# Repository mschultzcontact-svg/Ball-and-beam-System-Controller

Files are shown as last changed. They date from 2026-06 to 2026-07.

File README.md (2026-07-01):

# Automatisiertes Kugelbahn-System – Fokus: Balancer-Modul (Ball-on-Beam)

## Über das Projekt
Dieses Repository dokumentiert ein mechatronisches Folgeprojekt am Labor für Mechatronik und Regelungstechnik der Hochschule Osnabrück. 

Das Gesamtsystem ist als geschlossener Kreislauf konzipiert. Die Kugeln durchlaufen kontinuierlich eine dreiteilige, modular aufgebaute automatisierte Kugelbahn:

1. **Magazin & SmartSort-Modul:** Zu Beginn werden die Billardkugeln in einem Magazin gesammelt und von dort aus einzeln dem Sortierbereich zugeführt. Ein kamerabasiertes KI-System zur Bildverarbeitung erkennt die optischen Merkmale der Kugeln. Anhand dieser Klassifizierung ordnet ein 2-Achs-Handhabungsarm die Kugeln einer von drei Führungen zu.
2. **Rückführungsmodul:** Über diese Führungen rollen die Kugeln weiter zum Rückführungsmodul. Ein mechanischer Lift transportiert die Kugeln vertikal nach oben auf eine höhere Ebene, von wo aus sie eigenständig zum Vereinzeler des darauffolgenden Moduls rollen.
3. **Balancer-Modul (Ball-on-Beam):** Dieses Modul bildet den Kern und Schwerpunkt dieser Arbeit. Nach der gezielten Freigabe der Kugel durch den Vereinzeler gelangt diese auf eine bewegliche Wippe. Die Kugel wird entlang dieser 1,5 Meter langen Achse transportiert, während ein Schrittmotor den Neigungswinkel der Wippe kontinuierlich anpasst.

**Die Kernaufgabe meines Projekts:** Da dieses Kugel-auf-Balken-System inhärent instabil ist, besteht die Herausforderung darin, das System präzise zu regeln. Im Rahmen der Projektphase wird zunächst eine zentrale Steuerbox zur Signalverarbeitung und Motoransteuerung entwickelt (Teil I). Darauf aufbauend wird im Zuge der Bachelorarbeit eine robuste Regelungsstrategie mittels MATLAB-Simulation entworfen und an der realen Anlage in Betrieb genommen (Teil II), um einen dauerhaft fehlerfreien Kreislaufbetrieb zu garantieren.

---

## Repository-Struktur & Inhalt

Dieses Repository ist in funktionale Bereiche unterteilt. Nachfolgend finden Sie eine Übersicht, welche Inhalte und Daten in den jeweiligen Ordnern hinterlegt sind:

### 📁 01_Hardware
Hier befindet sich die vollständige elektrotechnische und mechanische Entwicklung der Steuerbox.
* **Datenblätter:** Technische Spezifikationen aller verwendeten Komponenten (z. B. Schrittmotor, ToF-Sensor, Mikrocontroller).
* **Schaltplan & Layout:** Die in KiCad entwickelten Platinen-Layouts (PCB), Schaltungsentwürfe sowie die Stücklisten (BOM) für die Fertigung.
* **Gehäuse:** CAD- und STL-Dateien für das Gehäuse der Steuerbox (optimiert für den 3D-Druck).

### 📁 02_Software_Firmware
Enthält den gesamten Programmcode für den realen Anlagenbetrieb sowie die Systemeinrichtung.
* **Steuerbox_Firmware:** Der produktive C/C++ Code für den Mikrocontroller, welcher im normalen Regelbetrieb die Sensorwerte einliest und den Motor ansteuert.
* **Kalibrierung:** Spezifische Testskripte zur Sensor- und Aktorkalibrierung, um Messfehler (z. B. des ToF-Sensors) vorab softwareseitig zu kompensieren.

### 📁 03_Modellierung_Simulation
Die theoretische und simulative Basis für den Reglerentwurf.
* **Modellierung:** Mathematische Herleitungen und die physikalischen Differentialgleichungen des Kugel-auf-Balken-Systems.
* **Matlab_Simulink:** `.m`-Skripte und `.slx`-Simulationsmodelle. Hier wird das System virtuell abgebildet, um Reglerstrukturen methodisch zu bedaten und eine Stabilitätsanalyse durchzuführen.
* **Messdaten:** Reale Protokolle und Schwingungsdaten aus der Anlage, die für den Abgleich zwischen Modell und Realität (Systemidentifikation) genutzt werden.

### 📁 04_Regelungsstrategie
Dokumentation und Code-Basis der untersuchten Regelungsansätze.
* Hier sind die verschiedenen evaluierten Regelungskonzepte hinterlegt (z. B. klassischer PID-Regler, Kaskadenregelung oder Zustandsregler). Es wird dokumentiert, wie die Strategien auf Störeinflüsse reagieren (z. B. beim transienten Eintritt der Kugel in das Modul) und welche Strategie die beste Stabilität liefert.

### 📁 05_Dokumentation
Begleitmaterialien und schriftliche Ausarbeitungen.
* Enthält den schriftlichen Projektbericht (Teil I: Steuerbox-Entwicklung & Teil II: Bachelorarbeit-Konzept inklusive Pflichtenheft und Projektplanung) sowie wichtige Systemgrafiken und Schaubilder.

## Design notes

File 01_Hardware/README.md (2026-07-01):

# 📁 Hardware-Entwicklung & Komponenten (Balancer-Modul)

Dieser Ordner enthält die vollständige elektrotechnische Dokumentation, das Platinen-Layout (KiCad) und die Spezifikationen der verwendeten Hardware-Komponenten für das Balancer-Modul (Ball-on-Beam).

## ⚡ Spannungsversorgung & Überwachung
Die primäre Energieeinspeisung der Steuerbox erfolgt über ein **24V-Hauptnetzteil** (Hauptversorgung für den Schrittmotor). Für die Logik- und Sensorpegel wird die Spannung über zwei **DC-DC-Wandler** heruntergeregelt:
* **24V ➡️ 9V:** Versorgung des Servomotors Wippe.
* **24V ➡️ 5V:** Versorgung der Servomotors Vereinzler.

**Spannungsüberwachung:** Die drei Spannungsschienen (24V, 9V, 5V) werden permanent überwacht. Da die ESP32-Eingänge nur maximal 3,3V tolerieren, sind präzise **SMD-Widerstände als Spannungsteiler** vorgeschaltet.

---

## 🧠 Dual-Controller-Architektur
Um harte Echtzeit-Regelung und Netzwerkkommunikation sauber zu trennen, basiert die Steuerbox auf zwei miteinander kommunizierenden ESP32-Modulen:

### 1. ESP32-S3-ETH (Host- & Kommunikations-Controller)
* **Aufgabe:** Übergeordnete Steuerung, Ethernet-Kommunikation mit den anderen Kugelbahn-Modulen (SmartSort / Rückführung) und Statusüberwachung.
* **Peripherie:** * Ansteuerung eines **TFT-Displays** zur Status- und Fehleranzeige.
  * Analoge Überwachung der Spannungsversorgung (5V, 9V, 24V).
  * Status-LEDs (inkl. Vorwiderständen) und 2x **Boot-Taster** für manuelle Eingriffe.

### 2. ESP32-DevKitC (Regelungs-Controller)
* **Aufgabe:** Läuft im **MATLAB/Simulink-Kompatibilitätsmodus**. Er liest in festen Zeitschritten die Sensorwerte ein, berechnet den Regelalgorithmus und steuert die Aktoren direkt an.
* **Kommunikation:** Direkter Datenaustausch mit dem ESP32-S3-ETH zur Zustandssynchronisation.

---

## 🛠️ Sensorik & Aktorik (Komponentenübersicht)

Die mechatronischen Komponenten des Moduls teilen sich in sensorische Erfassungsorgane und ausführende Aktoren auf:

* **Sensorik (Erfassung):**
  * **Kugelpositionssensor:** Kontinuierliche Erfassung der exakten Ist-Position der Kugel auf der 1,5 Meter langen Wippe als primäre Regelgröße.
  * **Hallsensor:** Erfasst den aktuellen Neigungswinkel der Wippen-Achse (Winkelmessung), um dem Regler die Orientierung der Bahn zurückzumelden.
  * **ToF-Sensor:** Optische Abstandsmessung via Lichtlaufzeit zur Kugeldetektion im Einlaufbereich des Vereinzeler-Moduls.
  * **Endschalter (Kugelaufnahme / Kugelabgabe):** Mechanische Taster zur sicheren Zustandserkennung, wenn eine Kugel das Modul betritt oder verlässt.

* **Aktorik (Ausführung):**
  * **Schrittmotor + DM556 Treiber:** Der Hauptantrieb zur hochpräzisen und dynamischen Verstellung des Neigungswinkels der Wippen-Linearachse.
  * **Servo-Vereinzeler:** Steuert die mechanische Freigabe der wartenden Kugeln vor dem Eintritt in die Regelstrecke.
  * **Servo-Wippe:** Ein zusätzlicher Stellmotor, welcher direkt an der Wippenmechanik für spezifische Stell- oder Arretieraufgaben zuständig ist.
---

## 📋 Datenblatt-Verzeichnis (Links)

Alle originalen Hersteller-Datenblätter sind im Unterordner `01_Datenblaetter/` hinterlegt:

| Komponente | Funktion im System | Dokument (Lokal) |
| :--- | :--- | :--- |
| **ESP32-S3-ETH** | Host, Ethernet & Display | [Datasheet_ESP32-S3-ETH.pdf](01_Datenblaetter/Datasheet_ESP32-S3-ETH.pdf) |
| **ESP32-DevKitC** | Simulink Echtzeit-Regler | [Datasheet_ESP32_DevKitC.pdf](01_Datenblaetter/Datasheet_ESP32_DevKitC.pdf) |
| **DM556** | Schrittmotortreiber | [Manual_DM556_Driver.pdf](01_Datenblaetter/Manual_DM556_Driver.pdf) |
| **ToF-Sensor** | Einlauf-Detektion | [Datasheet_ToF_Sensor.pdf](01_Datenblaetter/Datasheet_ToF_Sensor.pdf) |
| **DC-DC Wandler** | Spannungsregelung 5V / 9V | [Datasheet_DCDC_Converter.pdf](01_Datenblaetter/Datasheet_DCDC_Converter.pdf) |

---

## 📂 Ordnerinhalt
* `/01_Datenblaetter`: PDFs aller mechatronischen Komponenten.
* `/02_Schaltplan_Layout`: KiCad-Projektdateien, Schaltpläne (Schaltplan-Review), Gerber-Dateien für die Platinenfertigung und Stückliste (BOM).
* `/03_Gehaeuse`: CAD-Modelle und STL-Dateien für den 3D-Druck der Steuerbox.

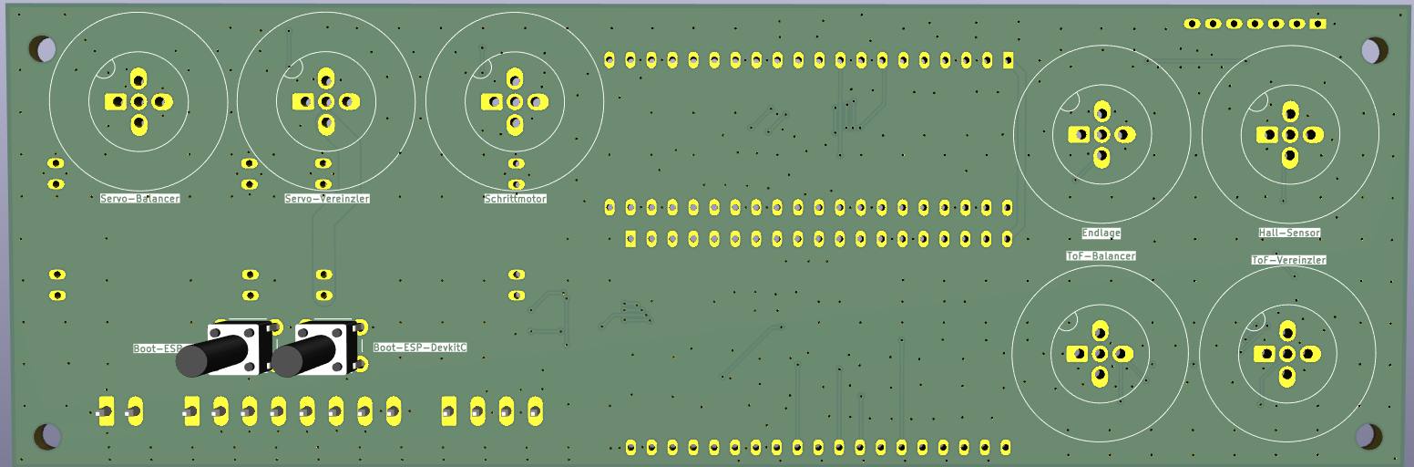
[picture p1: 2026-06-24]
01_Hardware/02_KiCad/Bilder_und_Schaltplan/Screenshot_Leiterplatte_3DAnsicht_Rückseite.png

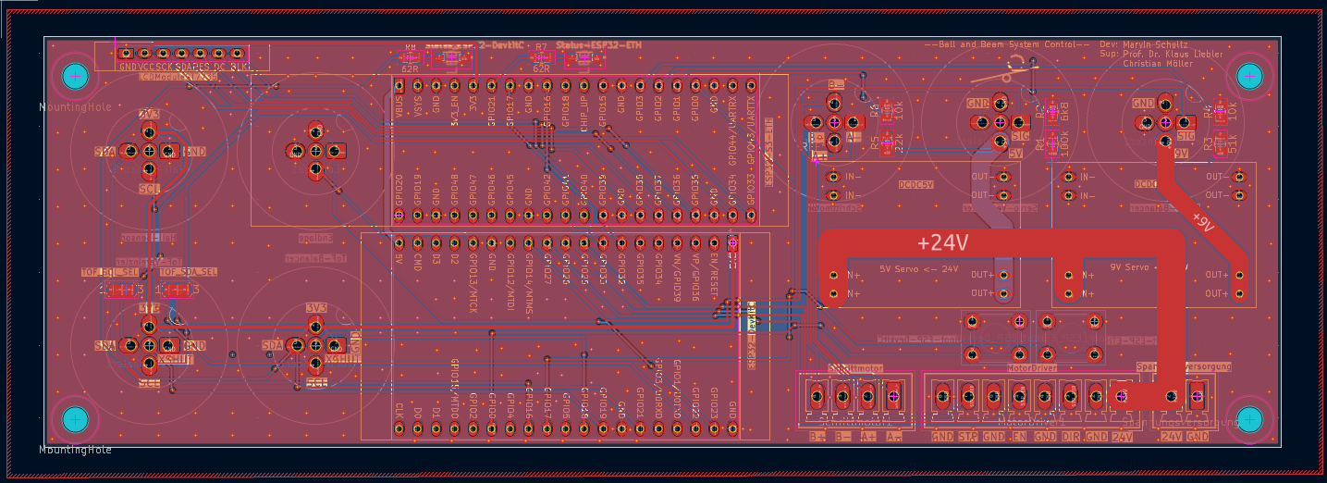
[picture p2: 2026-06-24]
01_Hardware/02_KiCad/Bilder_und_Schaltplan/Screenshot_Leiterplatte_Leiterplatteneditor.png

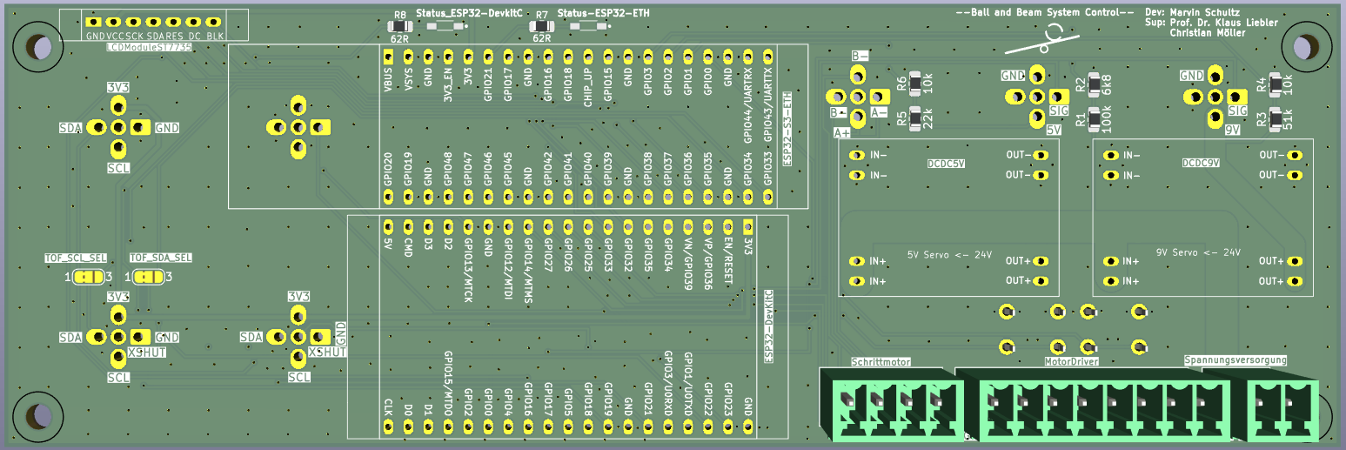
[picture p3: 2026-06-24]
01_Hardware/02_KiCad/Bilder_und_Schaltplan/Screenshot_Leiterplatte_3DAnsicht_Frontseite.png

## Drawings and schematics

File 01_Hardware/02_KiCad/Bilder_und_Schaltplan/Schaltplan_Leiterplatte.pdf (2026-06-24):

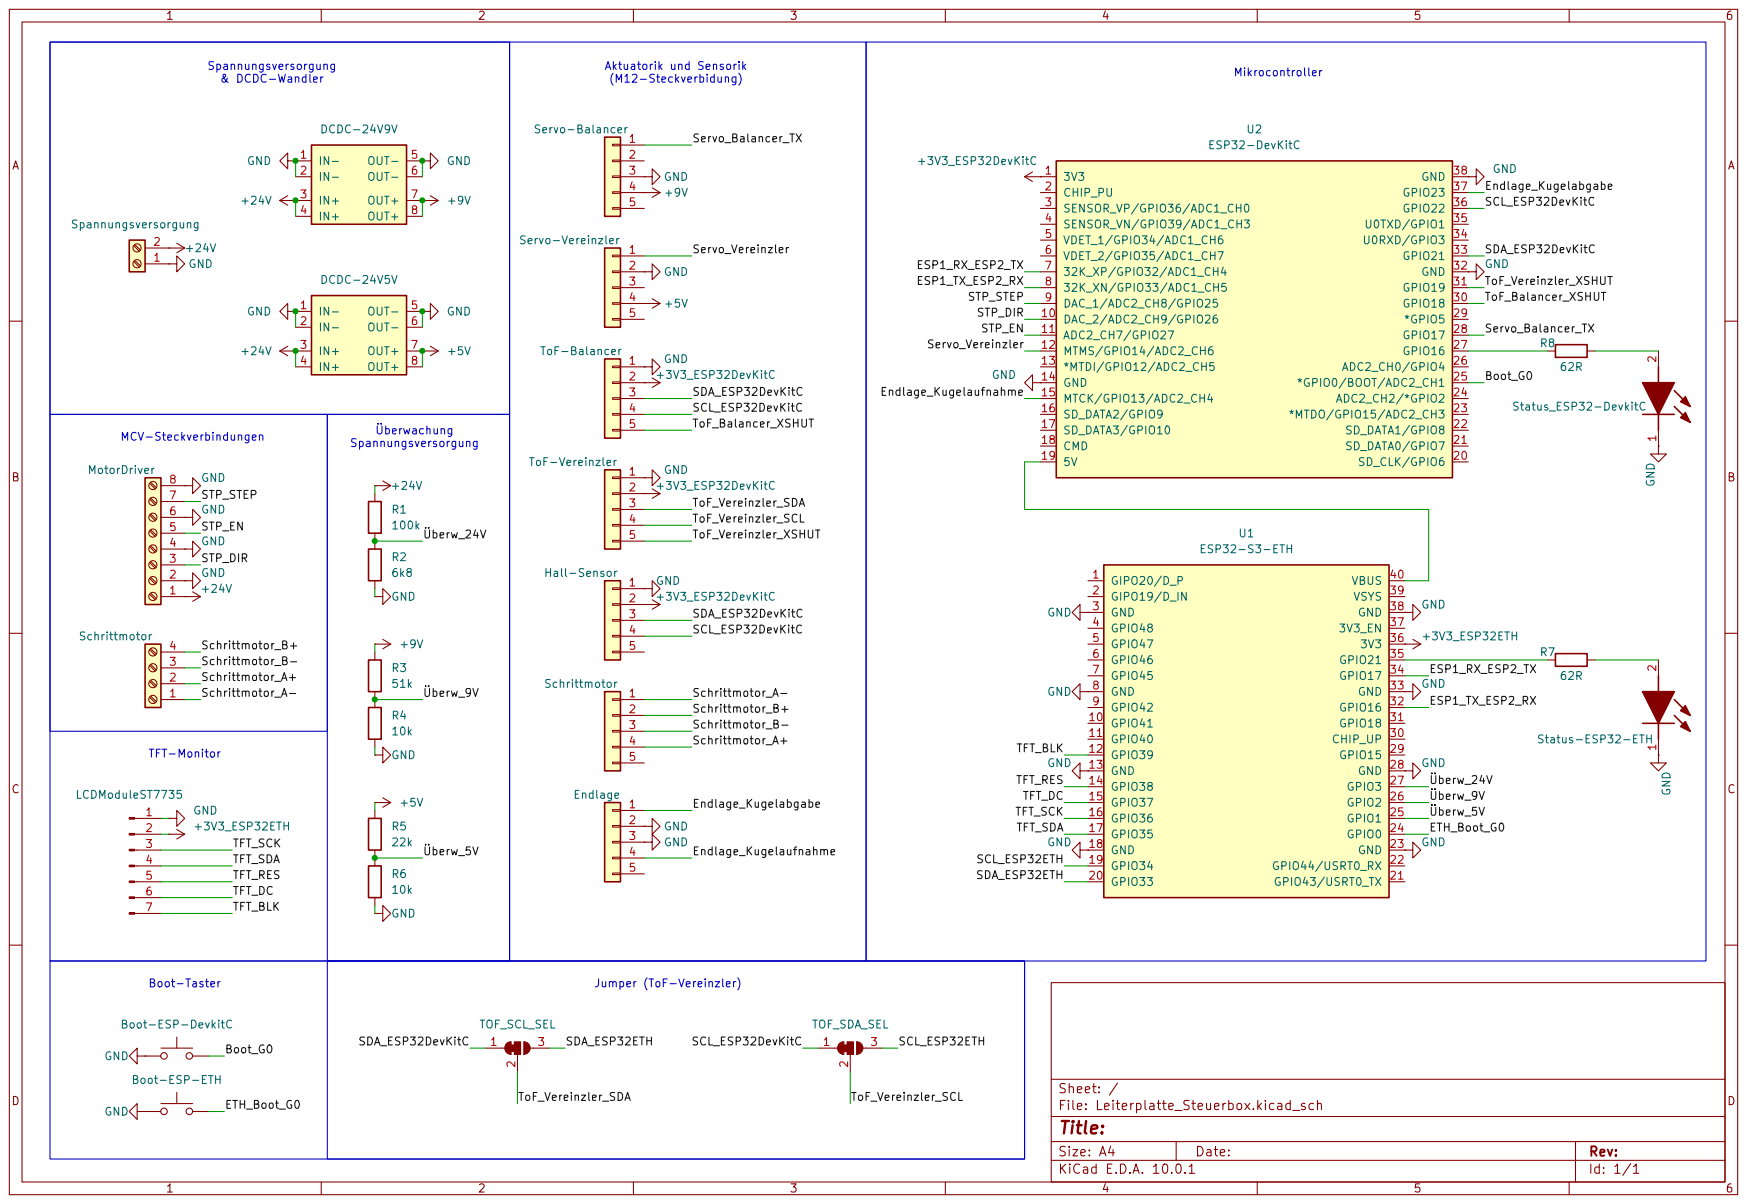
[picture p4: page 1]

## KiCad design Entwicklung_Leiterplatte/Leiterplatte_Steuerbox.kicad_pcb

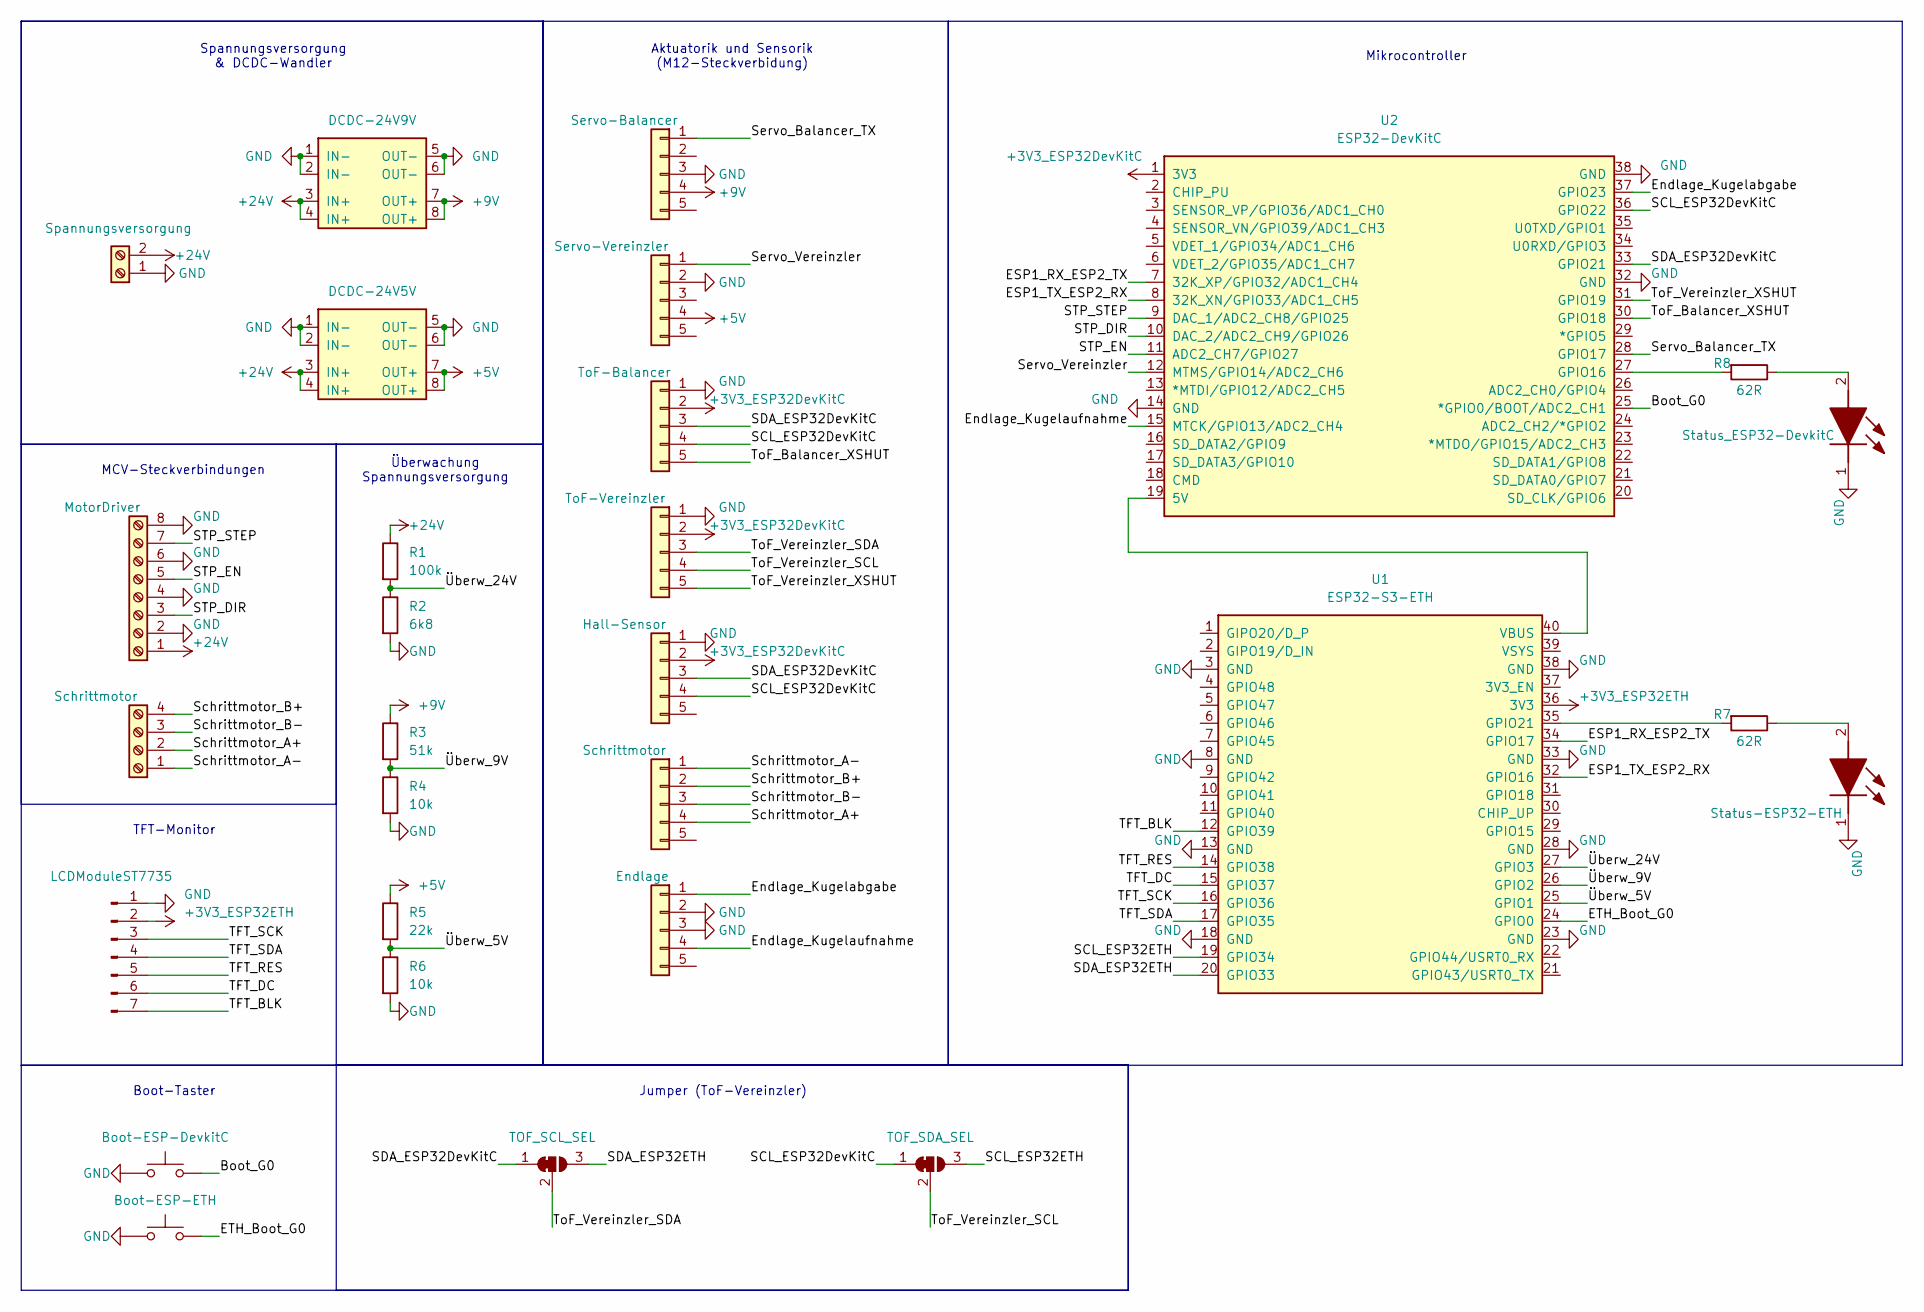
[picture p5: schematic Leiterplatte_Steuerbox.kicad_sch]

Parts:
Boot_ESP_DevkitC1: Boot-ESP-DevkitC; SW_PUSH_6mm_H13mm
Boot_ESP_ETH1: Boot-ESP-ETH; SW_PUSH_6mm_H13mm
DCDC-24V5V1: DCDC-24V5V; DCDC
DCDC-24V9V1: DCDC-24V9V; DCDC
Endlage1: Endlage; Liebler_Connector
Hall-Sensor1: Hall-Sensor; Liebler_Connector
JP1: TOF_SDA_SEL; SolderJumper-3_P1.3mm_Bridged2Bar12_RoundedPad1.0x1.5mm_Num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
JP2: TOF_SCL_SEL; SolderJumper-3_P1.3mm_Bridged2Bar12_RoundedPad1.0x1.5mm_Num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
LCDModuleST7735: Conn_01x07_Pin; TFT-Display
LED1: Status-ESP32-ETH; LSY876P2S11; Mouser Part Number 720-LSY876-P2S1-1-Z
LED2: Status_ESP32-DevkitC; LSY876P2S11; Mouser Part Number 720-LSY876-P2S1-1-Z
MotorDriver1: MotorDriver; PhoenixContact_MCV_1,5_8-G-3.5_1x08_P3.50mm_Vertical
R1: 100k; R_0805_2012Metric_Pad1.20x1.40mm_HandSolder
R2: 6k8; R_0805_2012Metric_Pad1.20x1.40mm_HandSolder
R3: 51k; R_0805_2012Metric_Pad1.20x1.40mm_HandSolder
R4, R6: 10k; R_0805_2012Metric_Pad1.20x1.40mm_HandSolder
R5: 22k; R_0805_2012Metric_Pad1.20x1.40mm_HandSolder
R7, R8: 62R; R_0805_2012Metric_Pad1.20x1.40mm_HandSolder
Schrittmotor1: Schrittmotor; PhoenixContact_MCV_1,5_4-G-3.5_1x04_P3.50mm_Vertical
Schrittmotor2: Schrittmotor; Liebler_Connector
ServoBalancer1: Servo-Balancer; Liebler_Connector
ServoVereinzler1: Servo-Vereinzler; Liebler_Connector
Spannungsversorgung1: Spannungsversorgung; PhoenixContact_MCV_1,5_2-G-3.5_1x02_P3.50mm_Vertical
ToF-Vereinzler1: ToF-Vereinzler; Liebler_Connector
ToFBalancer1: ToF-Balancer; Liebler_Connector
U1: ESP32-S3-ETH
U2: ESP32-DevKitC

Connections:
+3V3_ESP32DevKitC: Hall-Sensor1.2, ToF-Vereinzler1.2, ToFBalancer1.2, U2.1 (3V3)
+3V3_ESP32ETH: LCDModuleST7735.2, U1.36 (3V3)
+5V: DCDC-24V5V1.7 (OUT+), DCDC-24V5V1.8 (OUT+), R5.1, ServoVereinzler1.4
+9V: DCDC-24V9V1.7 (OUT+), DCDC-24V9V1.8 (OUT+), R3.1, ServoBalancer1.4
+24V: DCDC-24V5V1.3 (IN+), DCDC-24V5V1.4 (IN+), DCDC-24V9V1.3 (IN+), DCDC-24V9V1.4 (IN+), MotorDriver1.1, R1.1, Spannungsversorgung1.2
/Boot_G0: Boot_ESP_DevkitC1.2, U2.25 (*GPIO0/BOOT/ADC2_CH1)
/ESP1_RX_ESP2_TX: U1.34 (GPIO17), U2.7 (32K_XP/GPIO32/ADC1_CH4)
/ESP1_TX_ESP2_RX: U1.32 (GPIO16), U2.8 (32K_XN/GPIO33/ADC1_CH5)
/ETH_Boot_G0: Boot_ESP_ETH1.2, U1.24 (GPIO0)
/Endlage_Kugelabgabe: Endlage1.1, U2.37 (GPIO23)
/Endlage_Kugelaufnahme: Endlage1.4, U2.15 (MTCK/GPIO13/ADC2_CH4)
/SCL_ESP32DevKitC: Hall-Sensor1.4, JP1.1 (A), ToFBalancer1.4, U2.36 (GPIO22)
/SCL_ESP32ETH: JP1.3 (B), U1.19 (GPIO34)
/SDA_ESP32DevKitC: Hall-Sensor1.3, JP2.1 (A), ToFBalancer1.3, U2.33 (GPIO21)
/SDA_ESP32ETH: JP2.3 (B), U1.20 (GPIO33)
/STP_DIR: MotorDriver1.3, U2.10 (DAC_2/ADC2_CH9/GPIO26)
/STP_EN: MotorDriver1.5, U2.11 (ADC2_CH7/GPIO27)
/STP_STEP: MotorDriver1.7, U2.9 (DAC_1/ADC2_CH8/GPIO25)
/Schrittmotor_A+: Schrittmotor1.2, Schrittmotor2.4
/Schrittmotor_A-: Schrittmotor1.1, Schrittmotor2.1
/Schrittmotor_B+: Schrittmotor1.4, Schrittmotor2.2
/Schrittmotor_B-: Schrittmotor1.3, Schrittmotor2.3
/Servo_Balancer_TX: ServoBalancer1.1, U2.28 (GPIO17)
/Servo_Vereinzler: ServoVereinzler1.1, U2.12 (MTMS/GPIO14/ADC2_CH6)
/TFT_BLK: LCDModuleST7735.7, U1.12 (GPIO39)
/TFT_DC: LCDModuleST7735.6, U1.15 (GPIO37)
/TFT_RES: LCDModuleST7735.5, U1.14 (GPIO38)
/TFT_SCK: LCDModuleST7735.3, U1.16 (GPIO36)
/TFT_SDA: LCDModuleST7735.4, U1.17 (GPIO35)
/ToF_Balancer_XSHUT: ToFBalancer1.5, U2.30 (GPIO18)
/ToF_Vereinzler_SCL: JP1.2 (C), ToF-Vereinzler1.4
/ToF_Vereinzler_SDA: JP2.2 (C), ToF-Vereinzler1.3
/ToF_Vereinzler_XSHUT: ToF-Vereinzler1.5, U2.31 (GPIO19)
/Überw_5V: R5.2, R6.1, U1.25 (GPIO1)
/Überw_9V: R3.2, R4.1, U1.26 (GPIO2)
/Überw_24V: R1.2, R2.1, U1.27 (GPIO3)
GND: Boot_ESP_DevkitC1.1, Boot_ESP_ETH1.1, DCDC-24V5V1.1 (IN-), DCDC-24V5V1.2 (IN-), DCDC-24V5V1.5 (OUT-), DCDC-24V5V1.6 (OUT-), DCDC-24V9V1.1 (IN-), DCDC-24V9V1.2 (IN-), DCDC-24V9V1.5 (OUT-), DCDC-24V9V1.6 (OUT-), Endlage1.2, Endlage1.3, Hall-Sensor1.1, LCDModuleST7735.1, LED1.1 (K), LED2.1 (K), MotorDriver1.2, MotorDriver1.4, MotorDriver1.6, MotorDriver1.8, R2.2, R4.2, R6.2, ServoBalancer1.3, ServoVereinzler1.2, Spannungsversorgung1.1, ToF-Vereinzler1.1, ToFBalancer1.1, U1.3 (GND), U1.8 (GND), U1.13 (GND), U1.18 (GND), U1.23 (GND), U1.28 (GND), U1.33 (GND), U1.38 (GND), U2.14 (GND), U2.32 (GND), U2.38 (GND)
unnamed: LED1.2 (A), R7.1
unnamed: LED2.2 (A), R8.1
unnamed: R7.2, U1.35 (GPIO21)
unnamed: U1.40 (VBUS), U2.19 (5V)
unnamed: R8.2, U2.27 (GPIO16)

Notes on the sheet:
Boot-Taster
Überwachung Spannungsversorgung
Mikrocontroller
Spannungsversorgung & DCDC-Wandler
Aktuatorik und Sensorik (M12-Steckverbidung)
Jumper (ToF-Vereinzler)
MCV-Steckverbindungen
TFT-Monitor

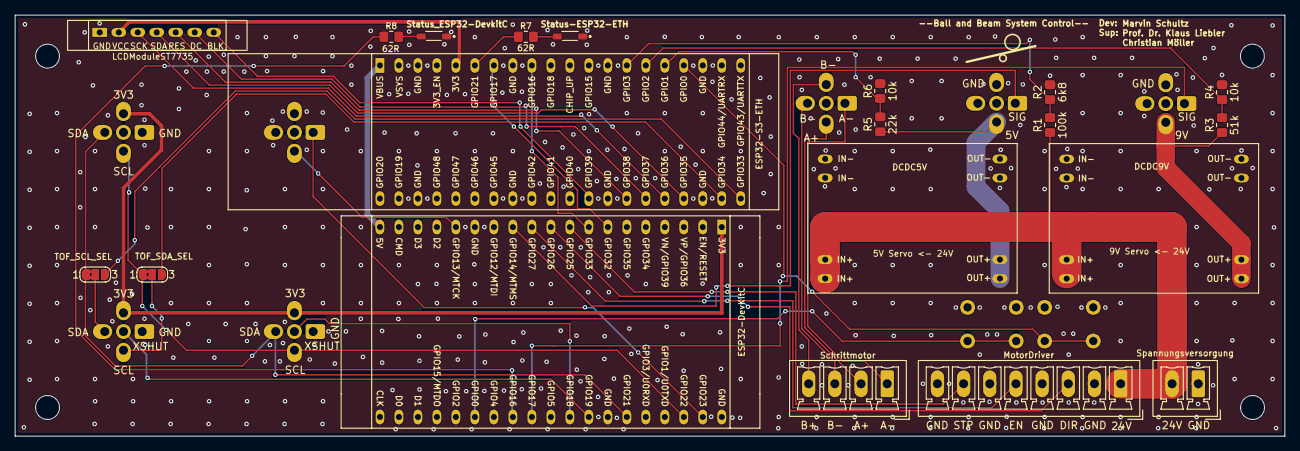
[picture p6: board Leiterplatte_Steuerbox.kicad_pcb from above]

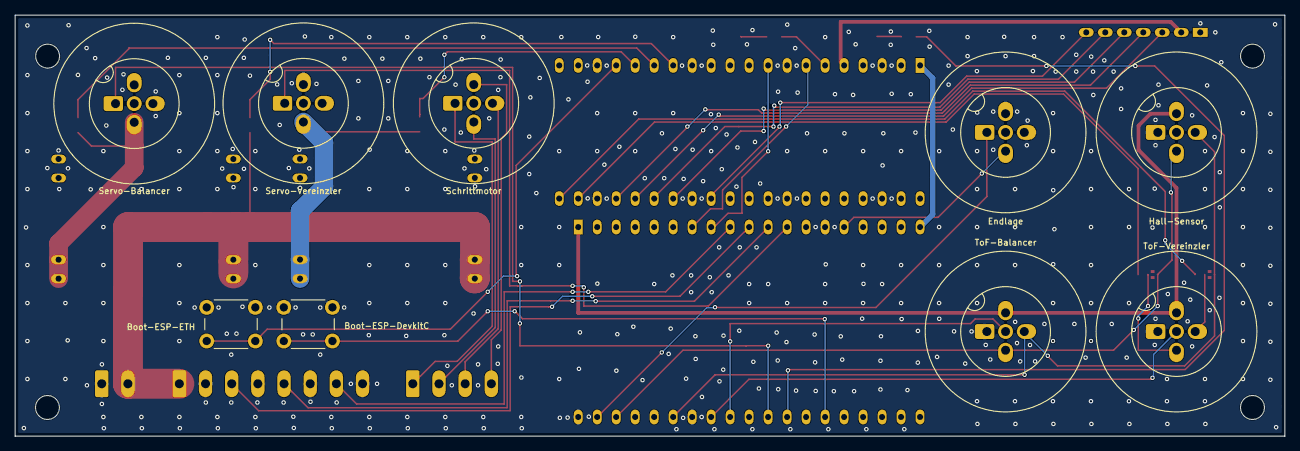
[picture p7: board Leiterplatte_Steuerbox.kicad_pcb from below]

Board: 2 copper layers, 169.8 x 56.3 mm, 33 parts (9 on the bottom side), 42 nets.

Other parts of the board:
H1, H2, H3, H4: MountingHole; MountingHole_3.2mm_M3
